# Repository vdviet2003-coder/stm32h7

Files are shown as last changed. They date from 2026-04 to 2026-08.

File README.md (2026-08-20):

# STM32H7 Sensorless FOC Motor Control

Firmware điều khiển động cơ PMSM theo phương pháp **Field-Oriented Control (FOC) không cảm biến vị trí (sensorless)** chạy trên vi điều khiển **STM32H723ZGTx**, sử dụng Sliding Mode Observer (SMO) để ước lượng góc và tốc độ rotor.

---
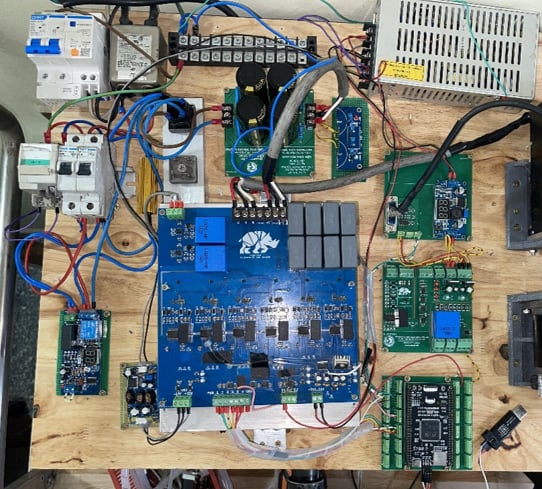
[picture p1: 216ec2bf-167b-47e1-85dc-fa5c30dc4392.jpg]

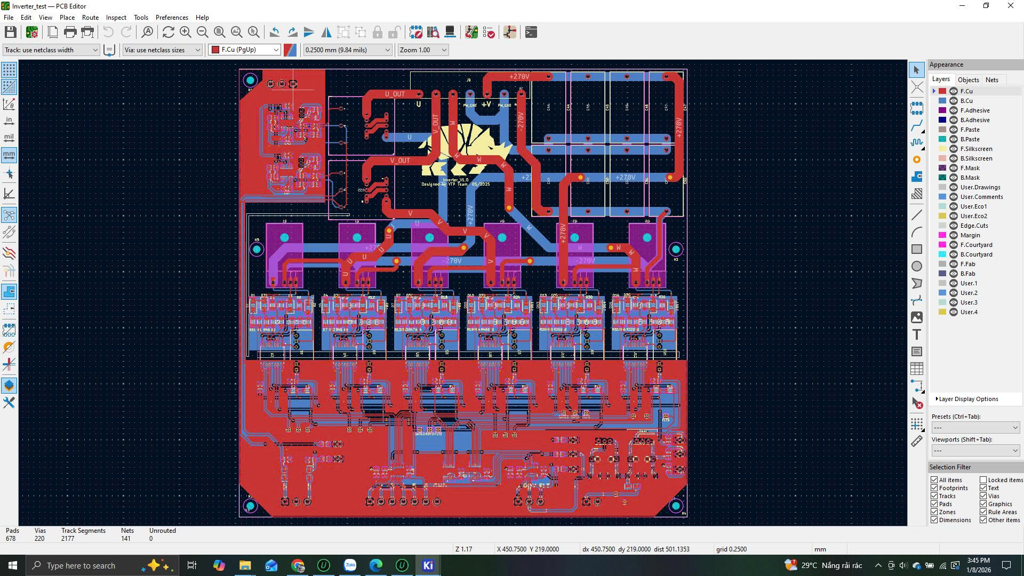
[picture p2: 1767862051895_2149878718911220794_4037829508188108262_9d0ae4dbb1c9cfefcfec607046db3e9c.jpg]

## Mục lục

1. [Tổng quan hệ thống](#1-tổng-quan-hệ-thống)
2. [Phần cứng và thông số động cơ](#2-phần-cứng-và-thông-số-động-cơ)
3. [Cấu trúc thư mục](#3-cấu-trúc-thư-mục)
4. [Sơ đồ khối điều khiển](#4-sơ-đồ-khối-điều-khiển)
5. [Luồng thực thi chính](#5-luồng-thực-thi-chính)
6. [Các module và logic chi tiết](#6-các-module-và-logic-chi-tiết)
   - 6.1 [conf.h – Cấu hình toàn cục](#61-confh--cấu-hình-toàn-cục)
   - 6.2 [FOC Transform – Clarke & Park](#62-foc-transform--clarke--park)
   - 6.3 [SVPWM – Space Vector PWM](#63-svpwm--space-vector-pwm)
   - 6.4 [ADC Driver – Đo dòng điện](#64-adc-driver--đo-dòng-điện)
   - 6.5 [Sensor – Hall & Encoder](#65-sensor--hall--encoder)
   - 6.6 [SMO – Sliding Mode Observer](#66-smo--sliding-mode-observer)
   - 6.7 [PID Controller](#67-pid-controller)
   - 6.8 [PI Clamping Controller](#68-pi-clamping-controller)
   - 6.9 [Speed Ramp Profiles](#69-speed-ramp-profiles)
   - 6.10 [UART DMA Library](#610-uart-dma-library)
7. [Máy trạng thái điều khiển (state machine)](#7-máy-trạng-thái-điều-khiển-state-machine)
   - 7.1 [Trạng thái chính (state)](#71-trạng-thái-chính-state)
   - 7.2 [Trạng thái SMO sensorless (state_smo)](#72-trạng-thái-smo-sensorless-state_smo)
8. [Cấu hình Timer và Ngắt](#8-cấu-hình-timer-và-ngắt)
9. [Thông số bộ điều khiển PID](#9-thông-số-bộ-điều-khiển-pid)
10. [Cấu hình Clock hệ thống](#10-cấu-hình-clock-hệ-thống)
11. [Build và nạp firmware](#11-build-và-nạp-firmware)

---

## 1. Tổng quan hệ thống

Hệ thống thực hiện điều khiển FOC hoàn chỉnh gồm 3 vòng điều khiển lồng nhau:

```
Tốc độ đặt (RPM/rad·s⁻¹)
        │
        ▼
  [Vòng tốc độ - PID]
        │  iq_ref
        ▼
  [Vòng dòng iq - PID] ──► vq
  [Vòng dòng id - PID] ──► vd    (id_ref = 0, kiểm soát từ thông)
        │
        ▼
  [Inv. Park] ──► vα, vβ
        │
        ▼
    [SVPWM] ──► TIM1 (PWM 3 pha)
        │
        ▼
     Động cơ
        │
        ▼
  [ADC] ─── iu, iv, iw
  [SMO] ─── θe, ωe  (sensorless)
        │
  [Clarke + Park] ──► id, iq (phản hồi)
```

---

## 2. Phần cứng và thông số động cơ

| Tham số | Giá trị |
|---|---|
| Vi điều khiển | STM32H723ZGTx |
| Toolchain | Keil MDK-ARM |
| Điện áp DC bus (VDC) | 60 V |
| Số cặp cực | 4 |
| Điện trở stator (Rs) | 5.83 Ω |
| Điện cảm stator (Ls) | 12.23 mH |
| Từ thông nam châm vĩnh cửu (ψf) | 0.0756 Wb |
| Tần số PWM | 20 kHz |
| Tần số vòng FOC | 40 kHz |
| Cảm biến dòng | LA-25-NP (Hall effect) |
| Điện trở đo | 120 Ω |
| Tỉ số biến đổi | 1:1000 (3 mA/A) |

### Phân công GPIO Hall sensor

| Tín hiệu | GPIO | Pin |
|---|---|-----|
| Hall U | GPIOD | PIN_12 |
| Hall V | GPIOD | PIN_13 |
| Hall W | GPIOD | PIN_14 |

---

## 3. Cấu trúc thư mục

```
no encoder/
└── GPIO/
    ├── Core/
    │   ├── Inc/           # Header STM32 HAL (adc.h, tim.h, gpio.h, ...)
    │   └── Src/
    │       ├── main.c     # Vòng lặp chính, FOC ISR, khởi tạo
    │       ├── adc.c      # Cấu hình ADC HAL (injected mode)
    │       ├── tim.c      # Cấu hình Timer HAL
    │       ├── gpio.c     # Cấu hình GPIO
    │       ├── dma.c      # Cấu hình DMA
    │       └── usart.c    # Cấu hình UART
    ├── MDK-ARM/           # Mã nguồn ứng dụng + project Keil
    │   ├── conf.h         # *** Toàn bộ thông số hệ thống ***
    │   ├── foc_transform.c/h   # Clarke, Park, Inv.Park transforms
    │   ├── svpwm.c/h           # SVPWM 6 sector + bù dead-time
    │   ├── adc_driver.c/h      # Đọc dòng từ LA-25-NP
    │   ├── sensor.c/h          # Hall sensor + Encoder ABZ
    │   ├── smo.c/h             # Sliding Mode Observer
    │   ├── pid.c/h             # PID Tustin + anti-windup
    │   ├── pi_control.c/h      # PI clamping
    │   ├── scurve_ramp.c/h     # S-curve tốc độ
    │   ├── multi_ramp.c/h      # Multi-segment ramp
    │   └── uart_dma_lib.c/h    # UART DMA gửi/nhận
    └── Drivers/
        ├── CMSIS/         # CMSIS core, DSP library
        └── STM32H7xx_HAL_Driver/  # HAL drivers
```

---

## 4. Sơ đồ khối điều khiển

```
                    ┌─────────────────────────────────────────────┐
                    │               FOC LOOP (40 kHz - TIM6)      │
                    │                                             │
speed_ref ──►[Ramp]──►[PID_speed]──► iq_ref                     │
                                        │                        │
              id_ref=0 ───────────────► [PID_id] ──► vd          │
                    iq_ref ──────────► [PID_iq] ──► vq           │
                                                     │           │
                                              [Inv.Park(θe)]     │
                                                     │           │
                                              [SVPWM] ──► TIM1   │
                                                                 │
    ADC ──► [Clarke] ──► iα,iβ ──► [Park(θe)] ──► id, iq        │
                  │                                              │
                  └──► [SMO] ──► θe, ωe (sensorless feedback)   │
                    └─────────────────────────────────────────────┘
```

---

## 5. Luồng thực thi chính

### `main()` – Khởi tạo một lần

```
1. MPU_Config()           – Cấu hình vùng bộ nhớ (DMA non-cacheable)
2. SystemClock_Config()   – PLL: HSE → 440 MHz SYSCLK
3. MX_*_Init()            – Khởi tạo tất cả ngoại vi HAL
4. SVPWM_Init()           – Cài đặt TIM1 center-aligned PWM
5. SVPWM_Start()          – Bật PWM 3 pha + complementary
6. ADC_Driver_Init()      – Khởi động ADC injected mode
7. ADC_Driver_CalibrateOffset() – Lấy 100,000 mẫu để tính offset
8. Hall_Sensor_Init()     – Đọc trạng thái Hall ban đầu
9. Encoder_Sensor_Init()  – Cấu hình TIM2 (encoder mode)
10. UART_DMA_Init()       – Bật UART1 DMA RX/TX
11. PID_Init(x3)          – Khởi tạo 3 vòng PID (Id, Iq, Speed)
12. SMO_Init()            – Khởi tạo Sliding Mode Observer
13. while(1) {}           – Vòng lặp trống (mọi xử lý qua ISR)
```

---

## 6. Các module và logic chi tiết

### 6.1 `conf.h` – Cấu hình toàn cục

File duy nhất chứa tất cả hằng số hệ thống. Thay đổi thông số ở đây sẽ tác động toàn bộ firmware.

```c
#define POLE_PAIRS          4.0f
#define MOTOR_PWM_FREQ      20000.0f   // Hz
#define MOTOR_SPEED_CALC_FREQ 40000.0f // Hz (vòng FOC)
#define MOTOR_RS            5.83f      // Ω
#define MOTOR_LS            0.01223f   // H
#define MOTOR_PSI_F         0.075595f  // Wb
#define VDC_BUS             60.0f      // V
```

---

### 6.2 FOC Transform – Clarke & Park

**File**: `foc_transform.c/h`

Thực hiện các phép biến đổi tọa độ cơ bản của FOC:

#### Clarke Transform (3 pha → αβ cố định)
$$i_\alpha = \frac{2}{3}i_u - \frac{1}{3}i_v - \frac{1}{3}i_w$$
$$i_\beta = \frac{1}{\sqrt{3}}(i_v - i_w)$$

#### Park Transform (αβ → dq quay theo rotor)
$$i_d = i_\alpha \cos\theta_e + i_\beta \sin\theta_e$$
$$i_q = -i_\alpha \sin\theta_e + i_\beta \cos\theta_e$$

#### Inverse Park (dq → αβ)
$$v_\alpha = v_d \cos\theta_e - v_q \sin\theta_e$$
$$v_\beta = v_d \sin\theta_e + v_q \cos\theta_e$$

> **Lưu ý**: Dùng biến đổi **amplitude-invariant** (không nhân 2/3), phù hợp với điều khiển dòng trực tiếp.

---

### 6.3 SVPWM – Space Vector PWM

**File**: `svpwm.c/h`

Thuật toán SVPWM 6 sector, center-aligned, với bù dead-time tự động.

#### Các bước tính toán:

1. **Xác định sector** – Dùng phương pháp dấu (Sign Method):
   ```
   U1 = Vβ
   U2 = (√3/2)·Vα - 0.5·Vβ
   U3 = -(√3/2)·Vα - 0.5·Vβ
   N = sign(U1) + 2·sign(U2) + 4·sign(U3)  → tra bảng sector_table[]
   ```

2. **Tính thời gian vector X, Y, Z** (chuẩn hóa):
   $$X = \frac{\sqrt{3} V_\beta}{V_{DC}}, \quad Y = \frac{1.5V_\alpha + 0.5\sqrt{3}V_\beta}{V_{DC}}, \quad Z = \frac{1.5V_\alpha - 0.5\sqrt{3}V_\beta}{V_{DC}}$$

3. **Gán Tx, Ty theo sector** và xử lý overmodulation (chuẩn hóa nếu Tx+Ty > 1)

4. **Tính duty cycle 3 pha**:
   $$T_a = 0.5 + \frac{V_\alpha}{V_{DC}}, \quad T_b = 0.5 + \frac{-0.5V_\alpha + \frac{\sqrt{3}}{2}V_\beta}{V_{DC}}$$

5. **Bù dead-time** (tự động theo chiều dòng điện):
   - Dead-time: 0.484 µs (= 133 chu kỳ / 275 MHz)
   - Điện áp diode: 0.8 V
   - Bù dương/âm tùy thuộc vào dấu dòng pha

6. **Ghi CCR** vào TIM1 (Center-aligned mode)

---

### 6.4 ADC Driver – Đo dòng điện

**File**: `adc_driver.c/h`

Đọc dòng điện từ 3 cảm biến **LA-25-NP** (Hall effect, ratio 1:1000) qua ADC injected mode đồng bộ với PWM.

#### Công thức chuyển đổi:
$$I_P = \frac{2 \cdot V_{ADC} + V_{offset}}{-R_m \cdot n} = \frac{2 \cdot V_{ADC} - 2.5}{-120 \times 0.003}$$

Trong đó:
- $V_{ADC}$: điện áp đọc từ ADC (0..3.3V)
- $V_{offset}$ = -2.5 V (điểm zero của cảm biến)
- $R_m$ = 120 Ω (điện trở đo)
- $n$ = 0.003 (tỉ số biến đổi = 3mA/A)

#### Hiệu chỉnh offset:
Khi khởi động, `ADC_Driver_CalibrateOffset()` lấy **100,000 mẫu** ở trạng thái không tải để xác định giá trị offset DC, bù vào các lần đọc sau.

---

### 6.5 Sensor – Hall & Encoder

**File**: `sensor.c/h`

#### Hall Sensor
- 3 bit Hall (U, V, W) → 6 bước (step 1..6)
- Mỗi bước tương ứng góc điện 60°
- `HallSensor_Update()` gọi trong `HAL_TIM_IC_CaptureCallback` (TIM4)
- `Sensor_Get_Electrical_Angle_Hall()` trả về góc điện (rad)

| Step | Góc điện |
|---|---|
| 1 | 0° |
| 2 | 60° |
| 3 | 120° |
| 4 | 180° |
| 5 | 240° |
| 6 | 300° |

#### Encoder ABZ
- TIM2 (32-bit) ở chế độ encoder quadrature
- 2500 PPR × 4 = 10,000 counts/vòng cơ
- `EncoderSensor_Update()` gọi trong TIM3 ISR (1 kHz)
- Hỗ trợ 3 phương pháp tính tốc độ:
  - **M method**: đếm xung trong thời gian cố định (tốc độ cao)
  - **T method**: đo thời gian giữa xung (tốc độ thấp)
  - **M/T method**: kết hợp hai phương pháp
  - **AUTO**: tự động chọn theo tốc độ

#### Bù trễ góc (Angle Prediction)
Trong vòng FOC, góc điện được dự đoán trước để bù trễ tính toán và ADC:
$$\theta_{pred} = \theta_{enc} + \omega_e \cdot (T_s + t_{delay})$$
Trong đó $t_{delay}$ = 3.87 µs (trễ ADC + tính toán).

---

### 6.6 SMO – Sliding Mode Observer

**File**: `smo.c/h`

Observer phi tuyến để ước lượng góc và tốc độ rotor **không cần encoder vật lý**. Triển khai theo mô hình dòng điện stator trong hệ tọa độ tĩnh αβ, kết hợp bộ lọc thông thấp và PLL để trích xuất sức phản điện (back-EMF).

---

#### Nguyên lý tổng quát

```
  [u_α, u_β]           [i_α, i_β]
       │                    │
       ▼                    │
  ┌─────────────────┐       │
  │  Mô hình dòng   │◄──────┘   (sai lệch → z_α, z_β)
  │  điện stator    │
  │  (Euler)        │──► [î_α, î_β]
  └────────┬────────┘
           │ z_α, z_β (sliding output)
           ▼
     [LPF 500 Hz]──► [ê_α, ê_β]  (back-EMF ước lượng)
           │
           ▼
       [PLL 200 Hz]──► θ_est, ω_est
           │
           ▼
   [Bù pha LPF]──► θ_compensated
```

---

#### Bước 1 – Hàm trượt (Sliding function) với deadzone

Để giảm chattering (dao động cao tần tại mặt trượt), hàm sign được thay bằng hàm tuyến tính trong vùng deadzone:

```c
static inline float sign_function(float x, float deadzone) {
    if      (x >  deadzone) return  1.0f;
    else if (x < -deadzone) return -1.0f;
    else                    return  x / deadzone;  // tuyến tính trong [-dz, +dz]
}
```

Ngõ ra khuếch đại trượt:

$$
z_{\alpha} = K_s \cdot \text{sign}(i_{\alpha,est} - i_{\alpha},\ 0.1\,\text{A})
$$

$$
z_{\beta} = K_s \cdot \text{sign}(i_{\beta,est} - i_{\beta},\ 0.1\,\text{A})
$$

Hệ số trượt $K_s$ chọn đủ lớn để đảm bảo điều kiện trượt:
$$K_s = 1.5 \cdot \omega_{max,elec} \cdot \psi_f \quad [\text{V}]$$

Ví dụ: $\omega_{max}$ = 3000 RPM × 4 pp × 2π/60 ≈ 1257 rad/s → $K_s = 1.5 \times 1257 \times 0.0756 \approx 142\,\text{V}$

---

#### Bước 2 – Mô hình dòng điện stator (tích phân Euler)

$$\hat{i}_{\alpha}[k+1] = \hat{i}_{\alpha}[k] + \frac{T_s}{L_s}\left(u_\alpha - R_s \hat{i}_{\alpha}[k] - z_\alpha\right)$$
$$\hat{i}_{\beta}[k+1]  = \hat{i}_{\beta}[k]  + \frac{T_s}{L_s}\left(u_\beta  - R_s \hat{i}_{\beta}[k]  - z_\beta\right)$$

Khi đạt chế độ trượt ($s_\alpha \to 0$, $s_\beta \to 0$), $z_\alpha \approx e_\alpha$ và $z_\beta \approx e_\beta$ (sức phản điện thực).

---

#### Bước 3 – Lọc thông thấp trích xuất back-EMF

Bộ lọc IIR bậc 1 (forward Euler) với $f_c$ = 500 Hz:

$$
\hat{e}_{\alpha}[k] = \alpha_f \cdot z_{\alpha} + (1-\alpha_f) \cdot \hat{e}_{\alpha}[k-1]
$$

$$
\hat{e}_{\beta}[k] = \alpha_f \cdot z_{\beta} + (1-\alpha_f) \cdot \hat{e}_{\beta}[k-1]
$$

Hệ số lọc:
$$\alpha_f = \frac{\omega_c T_s}{1 + \omega_c T_s}, \quad \omega_c = 2\pi \times 500 \approx 3141.6\,\text{rad/s}$$

Tại $T_s = 25\,\mu\text{s}$: $\alpha_f \approx 0.0728$

> **Lưu ý**: Bộ lọc thông thấp gây trễ pha phụ thuộc tốc độ, được bù lại ở bước 5.

---

#### Bước 4 – PLL ước lượng góc và tốc độ

Tín hiệu lỗi PLL (cross-product):

$$
\varepsilon = \hat{e}_{\beta} \cos\hat{\theta} - \hat{e}_{\alpha} \sin\hat{\theta}
$$

Khi hội tụ: $\hat{\theta} \to \theta_{real}$ → $\varepsilon \to 0$.

Bộ điều khiển PI của PLL:
$$\hat{\omega} = K_{p,PLL} \cdot \varepsilon + K_{i,PLL} \cdot \int \varepsilon \, dt$$

Tích phân góc (Euler):
$$\hat{\theta}[k+1] = \hat{\theta}[k] + \hat{\omega} \cdot T_s$$

Chuẩn hóa về $[0, 2\pi)$ sau mỗi bước.

**Anti-windup tốc độ**: khi $|\hat{\omega}| > \omega_{max}$, giới hạn cứng và reset tích phân:
```c
if (omega_pll > smo->omega_max) {
    omega_pll = smo->omega_max;
    smo->pll_integral = omega_pll / smo->Ki_pll;   // back-calculation
}
```

**Thông số PLL** (thiết kế theo $\zeta = 1/\sqrt{2}$, $f_n$ = 200 Hz):

| Tham số | Công thức | Giá trị |
|---|---|---|
| $\omega_n$ | $2\pi \times 200$ | 1256.6 rad/s |
| $K_{p,PLL}$ | $\sqrt{2} \cdot \omega_n$ | ≈ 1777 |
| $K_{i,PLL}$ | $\omega_n^2$ | ≈ 1.58 × 10⁶ |

---

#### Bước 5 – Bù pha bộ lọc thông thấp (`SMO_GetCompensatedTheta`)

Bộ lọc thông thấp 500 Hz gây trễ pha phụ thuộc tốc độ. Góc thực được bù động:
$$\phi_{delay} = \arctan\!\left(\frac{\hat{\omega}}{\omega_c}\right)$$
$$\theta_{comp} = \hat{\theta} + \phi_{delay}$$

```c
float SMO_GetCompensatedTheta(SMO_Handle *smo) {
    float wc = 2.0f * M_PI * smo->fc_filter;
    float phase_delay = atan2f(smo->omega_est, wc);
    return smo->theta_est + phase_delay;
}
```

> Khác với xấp xỉ cố định $+\pi/2$, cách này bù chính xác ở mọi tốc độ: khi $\hat{\omega} \ll \omega_c$ thì $\phi \to 0$; khi $\hat{\omega} \gg \omega_c$ thì $\phi \to \pi/2$.

---

#### Tóm tắt cấu trúc `SMO_Handle`

| Trường | Ý nghĩa | Đơn vị |
|---|---|---|
| `Rs`, `Ls`, `psi_f` | Thông số điện động cơ | Ω, H, Wb |
| `pole_pairs` | Số cặp cực | – |
| `Ks` | Hệ số khuếch đại trượt | V |
| `fc_filter`, `alpha_filter` | Bộ lọc LPF 500 Hz | Hz, – |
| `Kp_pll`, `Ki_pll` | Gains PI của PLL | – |
| `ialpha_est`, `ibeta_est` | Dòng ước lượng | A |
| `ealpha_est`, `ebeta_est` | Back-EMF ước lượng | V |
| `theta_est` | Góc điện ước lượng | rad |
| `omega_est` | Tốc độ điện ước lượng | rad/s |
| `pll_integral` | Tích phân PLL | – |
| `omega_max`, `omega_min` | Giới hạn tốc độ điện | rad/s |

---

#### API

| Hàm | Mô tả |
|-----|---|
| `SMO_Init(...)` | Khởi tạo, tự tính Ks, α_filter, Kp/Ki_pll |
| `SMO_Update(smo, uα, uβ, iα, iβ, dt)` | Gọi mỗi chu kỳ FOC (40 kHz) |
| `SMO_GetCompensatedTheta(smo)` | Trả về góc đã bù trễ LPF (rad) |
| `SMO_GetOmega(smo)` | Trả về tốc độ điện (rad/s) |
| `SMO_GetSpeedRPM(smo)` | Trả về tốc độ cơ (RPM) |

---

### 6.7 PID Controller

**File**: `pid.c/h`

Bộ điều khiển PID rời rạc dùng **Tustin (bilinear) discretization** để bảo toàn tính ổn định.

#### Rời rạc hóa Tustin:
$$u[k] = u[k-1] + \alpha \cdot e[k] + \beta \cdot e[k-1] + \gamma \cdot e[k-2]$$

Trong đó:
$$\alpha = K_p + \frac{K_i T}{2} + \frac{2K_d}{T}, \quad \beta = K_i T - \frac{4K_d}{T}, \quad \gamma = -K_p + \frac{K_i T}{2} + \frac{2K_d}{T}$$

#### Anti-windup:
Khi ngõ ra bão hòa (|u| = u_max), bộ tích phân tạm dừng (conditional integration).

---

### 6.8 PI Clamping Controller

**File**: `pi_control.c/h`

Bộ PI đơn giản với clamping (giới hạn cứng ngõ ra):
$$I_{prev} = I_{prev} + K_i \cdot T_s \cdot e$$
$$u = \text{clamp}(K_p \cdot e + I_{prev}, U_{min}, U_{max})$$

Dùng làm bộ điều khiển dự phòng thay thế cho PID trong trường hợp cần tuning nhanh.

---

### 6.9 Speed Ramp Profiles

#### S-Curve Ramp (`scurve_ramp.c/h`)
Tạo profile tốc độ dạng chữ S để tránh thay đổi đột ngột:
- Tham số: gia tốc tăng, gia tốc giảm, hằng số thời gian lọc τ
- Lọc exponential qua linear ramp → output mượt mà

#### Multi-Segment Ramp (`multi_ramp.c/h`)
Gia tốc khác nhau ở các vùng tốc độ khác nhau:
- Dưới ngưỡng (`threshold`): dùng `AccUp_1`, `AccDown_1` (gia tốc thấp vùng thấp tốc)
- Trên ngưỡng: dùng `AccUp_2`, `AccDown_2` (gia tốc cao vùng cao tốc)

Cấu hình mặc định: `threshold=5`, `up1=10`, `up2=10`, `down1=20`, `down2=20` (rad/s²)

---

### 6.10 UART DMA Library

**File**: `uart_dma_lib.c/h`

Giao tiếp UART1 bằng DMA không chặn (non-blocking):
- **TX**: Gửi chuỗi/dữ liệu qua DMA, không chờ
- **RX**: Nhận bằng DMA + IDLE interrupt để phát hiện kết thúc frame
- Hỗ trợ callback: `UART_DMA_RegisterRxCallback()` để xử lý dữ liệu nhận

---

## 7. Máy trạng thái điều khiển (State Machine)

### 7.1 Trạng thái chính (`state`)

Biến `state` điều khiển chế độ hoạt động của vòng FOC (TIM6 ISR, 40kHz):

```
┌─────────────────────────────────────────────────────────────────────┐
│  state = 0  │  DỪNG – PWM output = 0, reset SMO, tắt LED          │
├─────────────────────────────────────────────────────────────────────┤
│  state = 1  │  ALIGN – Căn chỉnh rotor:                           │
│             │  · InvPark(Id=0.8A, Iq=0, θ=0) → vα, vβ            │
│             │  · Reset encoder sau khi căn                         │
├─────────────────────────────────────────────────────────────────────┤
│  state = 2  │  CLOSED LOOP với Encoder:                           │
│             │  · Clarke → Park(θ_encoder_predicted)               │
│             │  · PID_speed → iq_ref                               │
│             │  · PID_iq, PID_id → vq, vd                         │
│             │  · InvPark → SVPWM                                  │
├─────────────────────────────────────────────────────────────────────┤
│  state = 3  │  OPEN LOOP điện áp:                                 │
│             │  · Dùng vd, vq đặt thủ công                        │
│             │  · InvPark(vd, vq, θ_encoder) → SVPWM              │
├─────────────────────────────────────────────────────────────────────┤
│  state = 4  │  SENSORLESS FOC (SMO):                             │
│             │  · 4 sub-state: ALIGN → OPENLOOP → SWITCH → RUN   │
└─────────────────────────────────────────────────────────────────────┘
```

### 7.2 Trạng thái SMO sensorless (`state_smo`)

Khi `state = 4`, máy trạng thái con `state_smo` quản lý quá trình khởi động sensorless:

```
       ┌─────────┐  ss_align_timer ≥ 1s   ┌────────────┐
  ───► │ SS_ALIGN│ ──────────────────────► │ SS_OPENLOOP│
       │         │                         │            │
       │Id=0.8A  │                         │Tăng ω mỗi  │
       │Iq=0     │                         │100rad/s²  │
       │θe = 0   │                         │            │
       └─────────┘                         └──────┬─────┘
                                                  │ ω ≥ ω_min
                                                  ▼
                                           ┌────────────┐
                                           │ SS_SWITCH  │
                                           │            │
                                           │Chờ SMO hội │
                                           │tụ: |î-i|  │
                                           │  < 0.3A   │
                                           └──────┬─────┘
                                                  │ hội tụ
                                                  ▼
                                           ┌────────────┐
                                           │  SS_RUN    │
                                           │            │
                                           │θe = SMO    │
                                           │ωe = SMO    │
                                           │PID_speed   │
                                           └────────────┘
```

#### Chi tiết từng sub-state:

| Sub-state | Góc θe | Dòng đặt | Điều kiện chuyển |
|---|---|---|---|
| `SS_ALIGN` | 0 rad (cố định) | Id=0.8A, Iq=0 | timer ≥ 1 giây |
| `SS_OPENLOOP` | Tăng dần (tích phân ω) | Id=0.8A, Iq=0 | ω_openloop ≥ ω_min (900 RPM × 4pp) |
| `SS_SWITCH` | Open-loop giữ nguyên | Id=0.8A, Iq=0 | \|î_α - i_α\| < 0.3A **và** \|î_β - i_β\| < 0.3A |
| `SS_RUN` | `SMO_GetCompensatedTheta()` | Id=0, Iq=PID_speed | – |

---

## 8. Cấu hình Timer và Ngắt

| Timer | Chức năng | Tần số / Mode |
|---|---|---|
| **TIM1** | SVPWM 3 pha + complementary | 20 kHz, center-aligned, PWM mode |
| **TIM2** | Encoder ABZ (32-bit) | Encoder interface mode, 10,000 cnt/rev |
| **TIM3** | Cập nhật tốc độ encoder | 1 kHz, base timer interrupt |
| **TIM4** | Hall sensor input capture | Capture trên cạnh lên của Hall |
| **TIM5** | Encoder capture (Z pulse) | Input capture channel 3 |
| **TIM6** | **FOC loop interrupt** | **40 kHz** – tất cả xử lý FOC |
| **TIM12** | Z-pulse (dự phòng) | – |

### ISR quan trọng

```c
// Gọi 40,000 lần/giây – xử lý FOC toàn bộ
void HAL_TIM_PeriodElapsedCallback(TIM_HandleTypeDef *htim) {
    if (htim->Instance == TIM6) {
        // 1. Đọc cảm biến (Hall, Encoder, ADC)
        // 2. Chạy máy trạng thái state/state_smo
        // 3. Clarke → Park → PID → InvPark → SVPWM
    }
    if (htim->Instance == TIM3) {
        EncoderSensor_Update();   // Tính tốc độ M/T
    }
}
```

---

## 9. Thông số bộ điều khiển PID

| Vòng | Kp | Ki | Kd | Giới hạn ngõ ra |
|---|----|----|----|---|
| **PID_id** (dòng d-axis) | 12.0 | 5830 | 0 | ±VDC/√3 = ±34.64 V |
| **PID_iq** (dòng q-axis) | 12.0 | 5830 | 0 | ±VDC/√3 = ±34.64 V |
| **PID_speed** (tốc độ) | 0.0053 | 2.37 | 0 | ±2.8 A |

> **Thiết kế vòng dòng**: Kp và Ki được tính theo phương pháp pole-zero cancellation:  
> $K_p = \frac{L_s}{\tau_{cl} \cdot T_s}$, $K_i = \frac{R_s}{\tau_{cl} \cdot T_s}$  
> với băng thông đóng $f_{cl}$ ~ 1 kHz.

---

## 10. Cấu hình Clock hệ thống

```
HSE (8 MHz) → PLL1:
  PLLM = 2  → VCI = 4 MHz
  PLLN = 44 → VCO = 176 MHz × 2 = 352 MHz  (wide VCO)
  PLLP = 1  → SYSCLK = 440 MHz
  AHB  /2   → HCLK  = 220 MHz
  APB1 /2   → PCLK1 = 110 MHz  (TIM2, TIM3, TIM4, TIM5, TIM6, TIM12)
  APB2 /2   → PCLK2 = 110 MHz  (TIM1, USART1)
```

- **Điện áp lõi**: Scale 0 (hiệu suất cao nhất)
- **Flash latency**: 3 wait states

---

## 11. Build và nạp firmware

### Yêu cầu
- **Keil MDK-ARM** v5.38 trở lên
- **STM32H7 Device Family Pack** (DFP)
- **ST-Link** hoặc J-Link debugger
- **CMSIS-DSP Library** (đã bao gồm trong `Drivers/CMSIS/DSP/`)

### Build
1. Mở `GPIO/MDK-ARM/GPIO.uvprojx` trong Keil uVision
2. Chọn target **GPIO**
3. Build: `F7` hoặc `Project → Build Target`

### Nạp và Debug
1. Kết nối ST-Link với board STM32H7
2. Flash: `Flash → Download` hoặc `F8`
3. Debug: `Debug → Start/Stop Debug Session` (`Ctrl+F5`)

### UART Monitor
- **UART1**, **115200 baud**, 8N1
- Khi khởi động, board gửi: `"UART DMA with IDLE+HT/TC ready\r\n"`
- Có thể gửi lệnh để thay đổi `state` và `speed_ref_rads`

---

## Ghi chú kỹ thuật

- **Dead-time**: 133 chu kỳ clock (≈ 0.484 µs tại 275 MHz APB) được bù tự động theo chiều dòng
- **ADC Injected mode**: ADC triggered đồng bộ với PWM (đỉnh counter TIM1) để lấy mẫu tại điểm tốt nhất (giữa thời gian dẫn)
- **Câu 3 pha từ 2 cảm biến**: `iw = -iu - iv` (định luật Kirchhoff), chỉ cần 2 cảm biến LA-25-NP vật lý
- **SMO ω_min**: 900 RPM × 4 cặp cực × 2π/60 ≈ 376 rad/s điện – tốc độ tối thiểu để SMO hội tụ ổn định
- **MPU**: Cấu hình vùng bộ nhớ DMA là non-cacheable để tránh data coherency issue với DMA

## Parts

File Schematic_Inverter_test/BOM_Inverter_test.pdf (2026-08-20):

Reference | Qty | Value
C1,C2,C3,C5,C8,C9,C10,C12,C15,C16,C17,C19,C22,C23,C24,C26,C29,C30,C31,C33,C36,C37,C38,C40,C69,C70 26 4.7u C4,C6,C11,C13,C18,C20,C25,C27,C32,C34,C39,C41,C53,C54,C55,C56,C57,C58 18 1u
C7,C14,C21,C28,C35,C42 | 6 220p
C43,C48,C67,C68 | 4 100n
C44,C45,C46,C47,C49,C50,C51,C52 8 106J
C59,C62,C63,C66 | 4 10u
C60,C61,C64,C65 | 4 1u
D1,D4,D7,D10,D13,D16,D22,D26,D27 9 B160-E3
D2,D5,D8,D11,D14,D17 | 6 D
D3,D6,D9,D12,D15,D18 | 6 D_Zener 4V7
D19,D20,D21,D23,D24,D25,D28,D29 8 LED
H1,H2,H3,H4 | 4 MountingHole
J1,J7 | 2 Screw_Terminal_01x03
J2 | 1 541V
J3 | 1 Screw_Terminal_01x07
J4 | 1 Alarm
J5 | 1 24V
J6,J8 | 2 Screw_Terminal_01x04
Q1,Q2,Q3,Q4,Q5,Q6 | 6 NC2M120C20HT
R1,R2,R7,R8,R13,R14,R19,R20,R25,R26,R31,R32,R45,R46,R47,R48,R49,R50,R51,R52,R53,R54,R55,R56 24 10 R3,R5,R9,R11,R15,R17,R21,R23,R27,R29,R33,R35,R37,R38 14 10k
R4,R10,R16,R22,R28,R34 | 6 10K
R6,R12,R18,R24,R30,R36,R71,R728 1K
R39,R40,R43 | 3 220
R41,R44 | 2 100
R42 | 1 1k5
R57,R58,R63,R64,R65,R66,R67,R68,R69,R70 10 10K
R59,R61 | 2 120k
R60,R62 | 2 160k
Rm1,Rm2 | 2 120
U1,U3,U5,U7,U9,U11 | 6 MGJ2D
U2,U4,U6,U8,U10,U12 | 6 1ED3321MC12NXUMA1
U13,U14 | 2 TXB0106PW
U15,U16 | 2 SN74HCS30PWR
U17 | 1 L7805
U18 | 1 LM1117T-3.3
U19,U20 | 2 LM385Z-ADJ
U21,U22 | 2 LA25-NP
U23,U24 | 2 OPA994IDR

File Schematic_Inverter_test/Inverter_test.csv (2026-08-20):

Reference | Qty | Value
24V1,FLT1,FLT2,FLT3,FLT4,FLT5,FLT6,GATE1,GATE2,GATE3,GATE4,GATE5,GATE6,GND1,RDY1,RDY2,RDY3,RDY4,RDY5,RDY6 | 20 | TestPoint
C1,C2,C3,C5,C8,C9,C10,C12,C15,C16,C17,C19,C22,C23,C24,C26,C29,C30,C31,C33,C36,C37,C38,C40,C69,C70 | 26 | 4.7u
C4,C6,C11,C13,C18,C20,C25,C27,C32,C34,C39,C41,C53,C54,C55,C56,C57,C58 | 18 | 1u
C7,C14,C21,C28,C35,C42 | 6 | 220p
C43,C48,C67,C68 | 4 | 100n
C44,C45,C46,C47,C49,C50,C51,C52 | 8 | 106J
C59,C62,C63,C66 | 4 | 10u t? hoá
C60,C61,C64,C65 | 4 | 1u t? k?o
D1,D4,D7,D10,D13,D16,D22,D26,D27,D30,D31,D32,D33,D34,D35 | 15 | Diode Shotky 5A 40V
D2,D5,D8,D11,D14,D17 | 6 | D th??ng
D3,D6,D9,D12,D15,D18 | 6 | D_Zener 10V
D19,D20,D21,D23,D24,D25,D28,D29 | 8 | LED
H1,H2,H3,H4,H5 | 5 | MountingHole
J1,J7 | 2 | Screw_Terminal_01x03
J3 | 1 | Screw_Terminal_01x07
J4 | 1 | Alarm
J5 | 1 | 24V
J9 | 1 | Screw_Terminal_01x07
Q1,Q2,Q3,Q4,Q5,Q6 | 6 | NC2M120C20HT
R1,R2,R7,R8,R13,R14,R19,R20,R25,R26,R31,R32,R45,R46,R47,R48,R49,R50,R51,R52,R53,R54,R55,R56 | 24 | 10R
R3,R5,R9,R11,R15,R17,R21,R23,R27,R29,R33,R35,R37,R38 | 14 | 10kR
R4,R10,R16,R22,R28,R34 | 6 | 10K
R6,R12,R18,R24,R30,R36,R71,R72 | 8 | 1K
R39,R40,R43 | 3 | 220R
R41,R44 | 2 | 100R
R42 | 1 | 1k5
R57,R58,R63,R64,R65,R66,R67,R68,R69,R70 | 10 | 10K
R59,R61 | 2 | 120k
R60,R62 | 2 | 160k
Rm1,Rm2 | 2 | 120R
U1,U3,U5,U7,U9,U11 | 6 | MGJ2D
U2,U4,U6,U8,U10,U12 | 6 | 1ED3321MC12NXUMA1
U13,U14 | 2 | TXB0106PW
U15,U16 | 2 | SN74HCS30PWR
U17 | 1 | L7805
U18 | 1 | LM1117T-3.3
U19,U20 | 2 | LM385Z-ADJ
U21,U22 | 2 | LA25-NP
U23,U24 | 2 | OPA994IDR

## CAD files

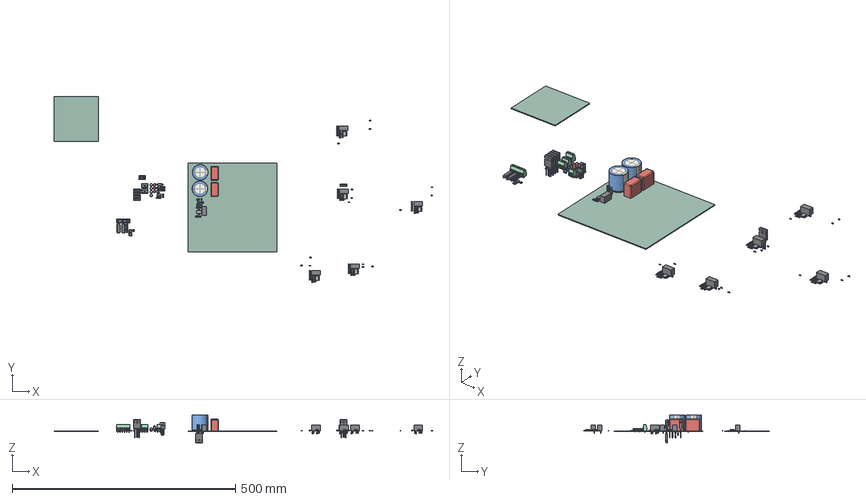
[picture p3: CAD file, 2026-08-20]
Schematic_Inverter_test/Inverter_test.step
848.2 x 415.3 x 62.0 mm
R_1206_3216Metric x 41
C_1206_3216Metric x 48
MGJ2_MUR x 6
LED_D5.0mm x 3
C_Disc_D5.0mm_W2.5mm_P5.00mm x 4
D_1206_3216Metric x 18
PG-DSO-16-40_INF x 6
CP_Radial_D35.0mm_P10.00mm_SnapIn x 2
TO-247-4_Vertical x 6
C_Rect_L31.5mm_W17.0mm_P27.50mm_MKS4 x 2
CP_Radial_D6.3mm_P2.50mm x 4
TO-220-3_Vertical x 2
TerminalBlock_Phoenix_MKDS-1,5-2_1x02_P5.00mm_Horizontal
TerminalBlock_Phoenix_MKDS-1,5-3_1x03_P5.00mm_Horizontal x 3
D_DO-27_P12.70mm_Horizontal
TSSOP-20_4.4x6.5mm_P0.65mm x 2
N14_TEX x 2
TerminalBlock_Phoenix_MKDS-1,5-6_1x06_P5.00mm_Horizontal
Inverter_test_copper
Inverter_test_silkscreen
Inverter_test_soldermask
Inverter_test_PCB_1
Inverter_test_PCB_2

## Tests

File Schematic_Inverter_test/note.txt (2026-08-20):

Min conductor Spacing ( khoảng cách tối thiểu )
+ 541V 	      :0.9251 mm  chọn 1mm
+ 24V,5V,3V3  :0.05   mm
Fusing Current (Dòng điện cháy đường dẫn)
+ 80A 	      : 6 mm
+ 6.5A	      : 0.6 mm
Conductor Properties (Đặc tính đường dẫn)

Thermal Management (Quản lý nhiệt)
Via Properties (Đặc tính lỗ thông tầng)
Conductor Impedance (Trở kháng đường dẫn)
Differential Pairs / XTALK (Cặp vi sai và nhiễu chéo)
PDN Calculator (Tính toán mạng phân phối điện)
Bandwidth & Max Er Effective Length (Băng thông và độ dài hiệu quả)

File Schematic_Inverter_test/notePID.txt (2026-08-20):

làm hàm code PID

gồm các biến như sau 
thời gian lấy mẫu: T
xung của encoder : EncoderCounter
Gía trị đặt : SetPoint
Gía trị hiện tại: CurrentPoint
Sai số hiện tại : E
Sai số trước đó 1 mẫu : E1
Sai số trước đó 2 mẫu : E2
các thông số của PID : alpha, beta, gamma, Kp,Kd,Ki;

xuất giá trị : Output,LastOutput

hàm PID
E = SetPoint - CurrentPoint
alpha = 2*T*Kp + K*T*T + 2*Kd
beta  = T*T*Ki - 4*Kd  - 2*T*Kp
gamma = 2*Kd

Output = ( alpha*E  + beta*E1 + gamma*E2 + 2*T*lastOutput)/(2*T);
lastOutput = Output
E2=E1
E1=E

hàm Park_1
Valfa = cos(Angle)*Vd - sin(Angle)*Vq
Vbeta = sin(Angle)*Vd + cos(Angle)*Vq
//
Id*cos(Angle)-Iq*sin(Angle)
Id*cos(Angle-2*pi/3)-Iq*sin(Angle-2*pi/3)
Id*cos(Angle+2*pi/3)-Iq*sin(Angle+2*pi/3)

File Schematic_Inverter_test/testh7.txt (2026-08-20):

/* USER CODE BEGIN Header */
/**
 ******************************************************************************
 * @file           : main.c
 * @brief          : Main program body
 ******************************************************************************
 * @attention
 *
 * Copyright (c) 2025 STMicroelectronics.
 * All rights reserved.
 *
 * This software is licensed under terms that can be found in the LICENSE file
 * in the root directory of this software component.
 * If no LICENSE file comes with this software, it is provided AS-IS.
 *
 ******************************************************************************
 */
/* USER CODE END Header */
/* Includes ------------------------------------------------------------------*/
#include "main.h"

/* Private includes ----------------------------------------------------------*/
/* USER CODE BEGIN Includes */
#include "arm_math.h"
#include "stdbool.h"
#include "stdio.h"
#include "stdlib.h"
#include "string.h"
/* USER CODE END Includes */

/* Private typedef -----------------------------------------------------------*/
/* USER CODE BEGIN PTD */
#define FSAMPLING    5000.0f     // tần số gọi SVPWM (5 kHz)
#define FOUT_TARGET  50.0f       // tần số điện áp mong muốn (Hz)
#define Pi 3.14159265359f

/* USER CODE END PTD */

/* Private define ------------------------------------------------------------*/
/* USER CODE BEGIN PD */

/* USER CODE END PD */

/* Private macro -------------------------------------------------------------*/
/* USER CODE BEGIN PM */

/* USER CODE END PM */

/* Private variables ---------------------------------------------------------*/

TIM_HandleTypeDef htim1;
TIM_HandleTypeDef htim3;

/* USER CODE BEGIN PV */
float Angle = 0.0f; // degree
float Angle_radian = 0.0f; // rad
float agl ; // // degree
float agl_radian ; // rad

float Vd = 0.0f;
float Vq = 5.0f;
float Vdc = 35.0f;
float Tperiod = 0.0f;
float Valpha , Vbeta , Vref ;
float Ta = 0.0f, Tb = 0.0f, T0 = 0.0f, T1 = 0.0f, T2 = 0.0f;
float u = 0.0f, v = 0.0f, w = 0.0f, g = 0.0f;
float Tsw1 = 0.0f, Tsw2 = 0.0f, Tsw3 = 0.0f;
uint8_t s;
/* USER CODE END PV */

/* Private function prototypes -----------------------------------------------*/
void SystemClock_Config(void);
static void MPU_Config(void);
static void MX_GPIO_Init(void);
static void MX_TIM1_Init(void);
static void MX_TIM3_Init(void);
/* USER CODE BEGIN PFP */

/* USER CODE END PFP */

/* Private user code ---------------------------------------------------------*/
/* USER CODE BEGIN 0 */
void Update_Tperiod(void)
{
    uint32_t tim_clk = 275000000;   // lấy clock thực tế của TIM1

    uint32_t prescaler = htim1.Init.Prescaler + 1U;
    uint32_t period    = htim1.Init.Period + 1U;

    // Nếu counter mode là center-aligned → period hiệu dụng gấp đôi
    if (htim1.Init.CounterMode == TIM_COUNTERMODE_CENTERALIGNED1 ||
        htim1.Init.CounterMode == TIM_COUNTERMODE_CENTERALIGNED2 ||
        htim1.Init.CounterMode == TIM_COUNTERMODE_CENTERALIGNED3)
    {
        period *= 2U;
    }

    Tperiod = ((float)prescaler * (float)period) / (float)tim_clk;
}
void SVPWM(void)
{
    Angle_radian = Angle * (Pi / 180.0f);
    Valpha = arm_cos_f32(Angle_radian) * Vd - arm_sin_f32(Angle_radian) * Vq;
    Vbeta  = arm_sin_f32(Angle_radian) * Vd + arm_cos_f32(Angle_radian) * Vq;

    arm_sqrt_f32(((Valpha * Valpha) + (Vbeta * Vbeta)), &Vref);
    agl_radian = atan2f(Vbeta, Valpha);
    agl = agl_radian * (180.0f / Pi);

    if (agl >= 0 && agl < 60)          
			s = 1;
    else if (agl >= 60 && agl < 120)   
			s = 2;
    else if (agl >= 120 && agl < 180)  
			s = 3;
    else if (agl >= -180 && agl < -120) 
			s = 4;
    else if (agl >= -120 && agl < -60)  
			s = 5;
    else if (agl >= -60 && agl < 0)     
			s = 6;
    else                 
			s = 0;

    // --- 4. Vector times ---
    Ta = T1 = (Tperiod * sqrtf(3.0f) / Vdc) * Vref *sinf((Pi * s / 3.0f) - agl_radian);

    Tb = T2 = (Tperiod * sqrtf(3.0f) / Vdc) * Vref *sinf(agl_radian - ((s - 1) * Pi / 3.0f));

    T0 = Tperiod - Ta - Tb;

    // --- 5. Intermediate values ---
    u = Tperiod - T0 / 2.0f;
    v = (T0 / 2.0f) + T2;
    w = T0 / 2.0f;
    g = (T0 / 2.0f) + T1;

    // --- 6. Switching times ---
    switch (s)
    {		
				case 0: Tsw1 = 0; Tsw2 = 0; Tsw3 = 0; break;
        case 1: Tsw1 = u; Tsw2 = v; Tsw3 = w; break;
        case 2: Tsw1 = g; Tsw2 = u; Tsw3 = w; break;
        case 3: Tsw1 = w; Tsw2 = u; Tsw3 = v; break;
        case 4: Tsw1 = w; Tsw2 = g; Tsw3 = u; break;
        case 5: Tsw1 = v; Tsw2 = w; Tsw3 = u; break;
        case 6: Tsw1 = u; Tsw2 = w; Tsw3 = g; break;
        
    }

    // --- 7. Mapping sang CCR ---
    uint32_t max_count = htim1.Init.Period;

    TIM1->CCR1 = (uint32_t)((Tsw1 / Tperiod) * max_count); // pha U
    TIM1->CCR2 = (uint32_t)((Tsw2 / Tperiod) * max_count); // pha V
    TIM1->CCR3 = (uint32_t)((Tsw3 / Tperiod) * max_count); // pha W

}

void HAL_TIM_PeriodElapsedCallback(TIM_HandleTypeDef *htim) {
    if (htim->Instance == TIM3) {
						SVPWM();
			        
    }
}
/* USER CODE END 0 */

/**
  * @brief  The application entry point.
  * @retval int
  */
int main(void)
{

  /* USER CODE BEGIN 1 */

  /* USER CODE END 1 */

  /* MPU Configuration--------------------------------------------------------*/
  MPU_Config();

  /* MCU Configuration--------------------------------------------------------*/

  /* Reset of all peripherals, Initializes the Flash interface and the Systick. */
  HAL_Init();

  /* USER CODE BEGIN Init */

  /* USER CODE END Init */

  /* Configure the system clock */
  SystemClock_Config();

  /* USER CODE BEGIN SysInit */

  /* USER CODE END SysInit */

  /* Initialize all configured peripherals */
  MX_GPIO_Init();
  MX_TIM1_Init();
  MX_TIM3_Init();
  /* USER CODE BEGIN 2 */
    HAL_TIM_PWM_Start(&htim1, TIM_CHANNEL_1);
    HAL_TIM_PWM_Start(&htim1, TIM_CHANNEL_2);
    HAL_TIM_PWM_Start(&htim1, TIM_CHANNEL_3);
    HAL_TIMEx_PWMN_Start(&htim1, TIM_CHANNEL_1);
    HAL_TIMEx_PWMN_Start(&htim1, TIM_CHANNEL_2);
    HAL_TIMEx_PWMN_Start(&htim1, TIM_CHANNEL_3);
    HAL_TIM_Base_Start_IT(&htim3);
		Update_Tperiod();
  /* USER CODE END 2 */

  /* Infinite loop */
  /* USER CODE BEGIN WHILE */
    while (1)
    {
    /* USER CODE END WHILE */

    /* USER CODE BEGIN 3 */
        HAL_GPIO_WritePin(GPIOA, GPIO_PIN_0, GPIO_PIN_SET);
    }
  /* USER CODE END 3 */
}

/**
  * @brief System Clock Configuration
  * @retval None
  */
void SystemClock_Config(void)
{
  RCC_OscInitTypeDef RCC_OscInitStruct = {0};
  RCC_ClkInitTypeDef RCC_ClkInitStruct = {0};

  /** Supply configuration update enable
  */
  HAL_PWREx_ConfigSupply(PWR_LDO_SUPPLY);

  /** Configure the main internal regulator output voltage
  */
  __HAL_PWR_VOLTAGESCALING_CONFIG(PWR_REGULATOR_VOLTAGE_SCALE0);

  while(!__HAL_PWR_GET_FLAG(PWR_FLAG_VOSRDY)) {}

  /** Initializes the RCC Oscillators according to the specified parameters
  * in the RCC_OscInitTypeDef structure.
  */
  RCC_OscInitStruct.OscillatorType = RCC_OSCILLATORTYPE_HSE;
  RCC_OscInitStruct.HSEState = RCC_HSE_ON;
  RCC_OscInitStruct.PLL.PLLState = RCC_PLL_ON;
  RCC_OscInitStruct.PLL.PLLSource = RCC_PLLSOURCE_HSE;
  RCC_OscInitStruct.PLL.PLLM = 2;
  RCC_OscInitStruct.PLL.PLLN = 44;
  RCC_OscInitStruct.PLL.PLLP = 1;
  RCC_OscInitStruct.PLL.PLLQ = 2;
  RCC_OscInitStruct.PLL.PLLR = 2;
  RCC_OscInitStruct.PLL.PLLRGE = RCC_PLL1VCIRANGE_3;
  RCC_OscInitStruct.PLL.PLLVCOSEL = RCC_PLL1VCOWIDE;
  RCC_OscInitStruct.PLL.PLLFRACN = 0;
  if (HAL_RCC_OscConfig(&RCC_OscInitStruct) != HAL_OK)
  {
    Error_Handler();
  }

  /** Initializes the CPU, AHB and APB buses clocks
  */
  RCC_ClkInitStruct.ClockType = RCC_CLOCKTYPE_HCLK|RCC_CLOCKTYPE_SYSCLK
                              |RCC_CLOCKTYPE_PCLK1|RCC_CLOCKTYPE_PCLK2
                              |RCC_CLOCKTYPE_D3PCLK1|RCC_CLOCKTYPE_D1PCLK1;
  RCC_ClkInitStruct.SYSCLKSource = RCC_SYSCLKSOURCE_PLLCLK;
  RCC_ClkInitStruct.SYSCLKDivider = RCC_SYSCLK_DIV1;
  RCC_ClkInitStruct.AHBCLKDivider = RCC_HCLK_DIV2;
  RCC_ClkInitStruct.APB3CLKDivider = RCC_APB3_DIV2;
  RCC_ClkInitStruct.APB1CLKDivider = RCC_APB1_DIV2;
  RCC_ClkInitStruct.APB2CLKDivider = RCC_APB2_DIV2;
  RCC_ClkInitStruct.APB4CLKDivider = RCC_APB4_DIV2;

  if (HAL_RCC_ClockConfig(&RCC_ClkInitStruct, FLASH_LATENCY_3) != HAL_OK)
  {
    Error_Handler();
  }
}

/**
  * @brief TIM1 Initialization Function
  * @param None
  * @retval None
  */
static void MX_TIM1_Init(void)
{

  /* USER CODE BEGIN TIM1_Init 0 */

  /* USER CODE END TIM1_Init 0 */

  TIM_ClockConfigTypeDef sClockSourceConfig = {0};
  TIM_MasterConfigTypeDef sMasterConfig = {0};
  TIM_OC_InitTypeDef sConfigOC = {0};
  TIM_BreakDeadTimeConfigTypeDef sBreakDeadTimeConfig = {0};

  /* USER CODE BEGIN TIM1_Init 1 */

  /* USER CODE END TIM1_Init 1 */
  htim1.Instance = TIM1;
  htim1.Init.Prescaler = 0;
  htim1.Init.CounterMode = TIM_COUNTERMODE_CENTERALIGNED1;
  htim1.Init.Period = 13749;
  htim1.Init.ClockDivision = TIM_CLOCKDIVISION_DIV2;
  htim1.Init.RepetitionCounter = 0;
  htim1.Init.AutoReloadPreload = TIM_AUTORELOAD_PRELOAD_DISABLE;
  if (HAL_TIM_Base_Init(&htim1) != HAL_OK)
  {
    Error_Handler();
  }
  sClockSourceConfig.ClockSource = TIM_CLOCKSOURCE_INTERNAL;
  if (HAL_TIM_ConfigClockSource(&htim1, &sClockSourceConfig) != HAL_OK)
  {
    Error_Handler();
  }
  if (HAL_TIM_PWM_Init(&htim1) != HAL_OK)
  {
    Error_Handler();
  }
  sMasterConfig.MasterOutputTrigger = TIM_TRGO_RESET;
  sMasterConfig.MasterOutputTrigger2 = TIM_TRGO2_RESET;
  sMasterConfig.MasterSlaveMode = TIM_MASTERSLAVEMODE_DISABLE;
  if (HAL_TIMEx_MasterConfigSynchronization(&htim1, &sMasterConfig) != HAL_OK)
  {
    Error_Handler();
  }
  sConfigOC.OCMode = TIM_OCMODE_PWM1;
  sConfigOC.Pulse = 0;
  sConfigOC.OCPolarity = TIM_OCPOLARITY_HIGH;
  sConfigOC.OCNPolarity = TIM_OCNPOLARITY_HIGH;
  sConfigOC.OCFastMode = TIM_OCFAST_DISABLE;
  sConfigOC.OCIdleState = TIM_OCIDLESTATE_RESET;
  sConfigOC.OCNIdleState = TIM_OCNIDLESTATE_RESET;
  if (HAL_TIM_PWM_ConfigChannel(&htim1, &sConfigOC, TIM_CHANNEL_1) != HAL_OK)
  {
    Error_Handler();
  }
  if (HAL_TIM_PWM_ConfigChannel(&htim1, &sConfigOC, TIM_CHANNEL_2) != HAL_OK)
  {
    Error_Handler();
  }
  if (HAL_TIM_PWM_ConfigChannel(&htim1, &sConfigOC, TIM_CHANNEL_3) != HAL_OK)
  {
    Error_Handler();
  }
  sBreakDeadTimeConfig.OffStateRunMode = TIM_OSSR_DISABLE;
  sBreakDeadTimeConfig.OffStateIDLEMode = TIM_OSSI_DISABLE;
  sBreakDeadTimeConfig.LockLevel = TIM_LOCKLEVEL_OFF;
  sBreakDeadTimeConfig.DeadTime = 100;
  sBreakDeadTimeConfig.BreakState = TIM_BREAK_DISABLE;
  sBreakDeadTimeConfig.BreakPolarity = TIM_BREAKPOLARITY_HIGH;
  sBreakDeadTimeConfig.BreakFilter = 0;
  sBreakDeadTimeConfig.Break2State = TIM_BREAK2_DISABLE;
  sBreakDeadTimeConfig.Break2Polarity = TIM_BREAK2POLARITY_HIGH;
  sBreakDeadTimeConfig.Break2Filter = 0;
  sBreakDeadTimeConfig.AutomaticOutput = TIM_AUTOMATICOUTPUT_DISABLE;
  if (HAL_TIMEx_ConfigBreakDeadTime(&htim1, &sBreakDeadTimeConfig) != HAL_OK)
  {
    Error_Handler();
  }
  /* USER CODE BEGIN TIM1_Init 2 */

  /* USER CODE END TIM1_Init 2 */
  HAL_TIM_MspPostInit(&htim1);

}

/**
  * @brief TIM3 Initialization Function
  * @param None
  * @retval None
  */
static void MX_TIM3_Init(void)
{

  /* USER CODE BEGIN TIM3_Init 0 */

  /* USER CODE END TIM3_Init 0 */

  TIM_ClockConfigTypeDef sClockSourceConfig = {0};
  TIM_MasterConfigTypeDef sMasterConfig = {0};

  /* USER CODE BEGIN TIM3_Init 1 */

  /* USER CODE END TIM3_Init 1 */
  htim3.Instance = TIM3;
  htim3.Init.Prescaler = 0;
  htim3.Init.CounterMode = TIM_COUNTERMODE_UP;
  htim3.Init.Period = 54999;
  htim3.Init.ClockDivision = TIM_CLOCKDIVISION_DIV1;
  htim3.Init.AutoReloadPreload = TIM_AUTORELOAD_PRELOAD_DISABLE;
  if (HAL_TIM_Base_Init(&htim3) != HAL_OK)
  {
    Error_Handler();
  }
  sClockSourceConfig.ClockSource = TIM_CLOCKSOURCE_INTERNAL;
  if (HAL_TIM_ConfigClockSource(&htim3, &sClockSourceConfig) != HAL_OK)
  {
    Error_Handler();
  }
  sMasterConfig.MasterOutputTrigger = TIM_TRGO_RESET;
  sMasterConfig.MasterSlaveMode = TIM_MASTERSLAVEMODE_DISABLE;
  if (HAL_TIMEx_MasterConfigSynchronization(&htim3, &sMasterConfig) != HAL_OK)
  {
    Error_Handler();
  }
  /* USER CODE BEGIN TIM3_Init 2 */

  /* USER CODE END TIM3_Init 2 */

}

/**
  * @brief GPIO Initialization Function
  * @param None
  * @retval None
  */
static void MX_GPIO_Init(void)
{
  GPIO_InitTypeDef GPIO_InitStruct = {0};
  /* USER CODE BEGIN MX_GPIO_Init_1 */

  /* USER CODE END MX_GPIO_Init_1 */

  /* GPIO Ports Clock Enable */
  __HAL_RCC_GPIOH_CLK_ENABLE();
  __HAL_RCC_GPIOA_CLK_ENABLE();
  __HAL_RCC_GPIOE_CLK_ENABLE();

  /*Configure GPIO pin Output Level */
  HAL_GPIO_WritePin(GPIOA, GPIO_PIN_0, GPIO_PIN_RESET);

  /*Configure GPIO pin : PA0 */
  GPIO_InitStruct.Pin = GPIO_PIN_0;
  GPIO_InitStruct.Mode = GPIO_MODE_OUTPUT_PP;
  GPIO_InitStruct.Pull = GPIO_NOPULL;
  GPIO_InitStruct.Speed = GPIO_SPEED_FREQ_LOW;
  HAL_GPIO_Init(GPIOA, &GPIO_InitStruct);

  /*AnalogSwitch Config */
  HAL_SYSCFG_AnalogSwitchConfig(SYSCFG_SWITCH_PA0, SYSCFG_SWITCH_PA0_CLOSE);

  /* USER CODE BEGIN MX_GPIO_Init_2 */

  /* USER CODE END MX_GPIO_Init_2 */
}

/* USER CODE BEGIN 4 */

/* USER CODE END 4 */

 /* MPU Configuration */

void MPU_Config(void)
{
  MPU_Region_InitTypeDef MPU_InitStruct = {0};

  /* Disables the MPU */
  HAL_MPU_Disable();

  /** Initializes and configures the Region and the memory to be protected
  */
  MPU_InitStruct.Enable = MPU_REGION_ENABLE;
  MPU_InitStruct.Number = MPU_REGION_NUMBER0;
  MPU_InitStruct.BaseAddress = 0x0;
  MPU_InitStruct.Size = MPU_REGION_SIZE_4GB;
  MPU_InitStruct.SubRegionDisable = 0x87;
  MPU_InitStruct.TypeExtField = MPU_TEX_LEVEL0;
  MPU_InitStruct.AccessPermission = MPU_REGION_NO_ACCESS;
  MPU_InitStruct.DisableExec = MPU_INSTRUCTION_ACCESS_DISABLE;
  MPU_InitStruct.IsShareable = MPU_ACCESS_SHAREABLE;
  MPU_InitStruct.IsCacheable = MPU_ACCESS_NOT_CACHEABLE;
  MPU_InitStruct.IsBufferable = MPU_ACCESS_NOT_BUFFERABLE;

  HAL_MPU_ConfigRegion(&MPU_InitStruct);
  /* Enables the MPU */
  HAL_MPU_Enable(MPU_PRIVILEGED_DEFAULT);

}

/**
  * @brief  This function is executed in case of error occurrence.
  * @retval None
  */
void Error_Handler(void)
{
  /* USER CODE BEGIN Error_Handler_Debug */
    /* User can add his own implementation to report the HAL error return state */
    __disable_irq();
    while (1)
    {
    }
  /* USER CODE END Error_Handler_Debug */
}

#ifdef  USE_FULL_ASSERT
/**
  * @brief  Reports the name of the source file and the source line number
  *         where the assert_param error has occurred.
  * @param  file: pointer to the source file name
  * @param  line: assert_param error line source number
  * @retval None
  */
void assert_failed(uint8_t *file, uint32_t line)
{
  /* USER CODE BEGIN 6 */
    /* User can add his own implementation to report the file name and line number,
       ex: printf("Wrong parameters value: file %s on line %d\r\n", file, line) */
  /* USER CODE END 6 */
}
#endif /* USE_FULL_ASSERT */

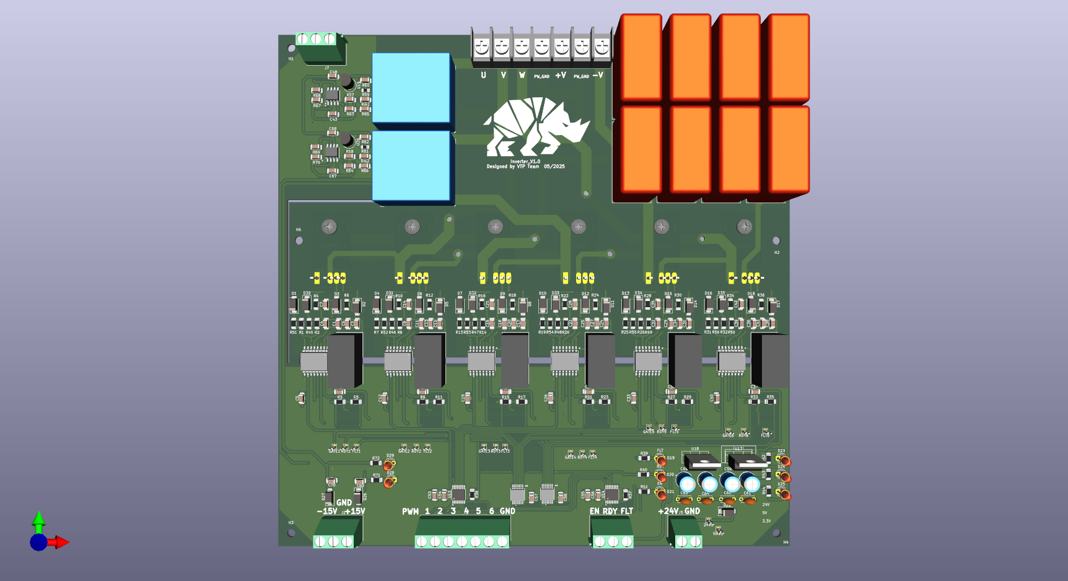
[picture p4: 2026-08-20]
Schematic_Inverter_test/Inverter_test.png

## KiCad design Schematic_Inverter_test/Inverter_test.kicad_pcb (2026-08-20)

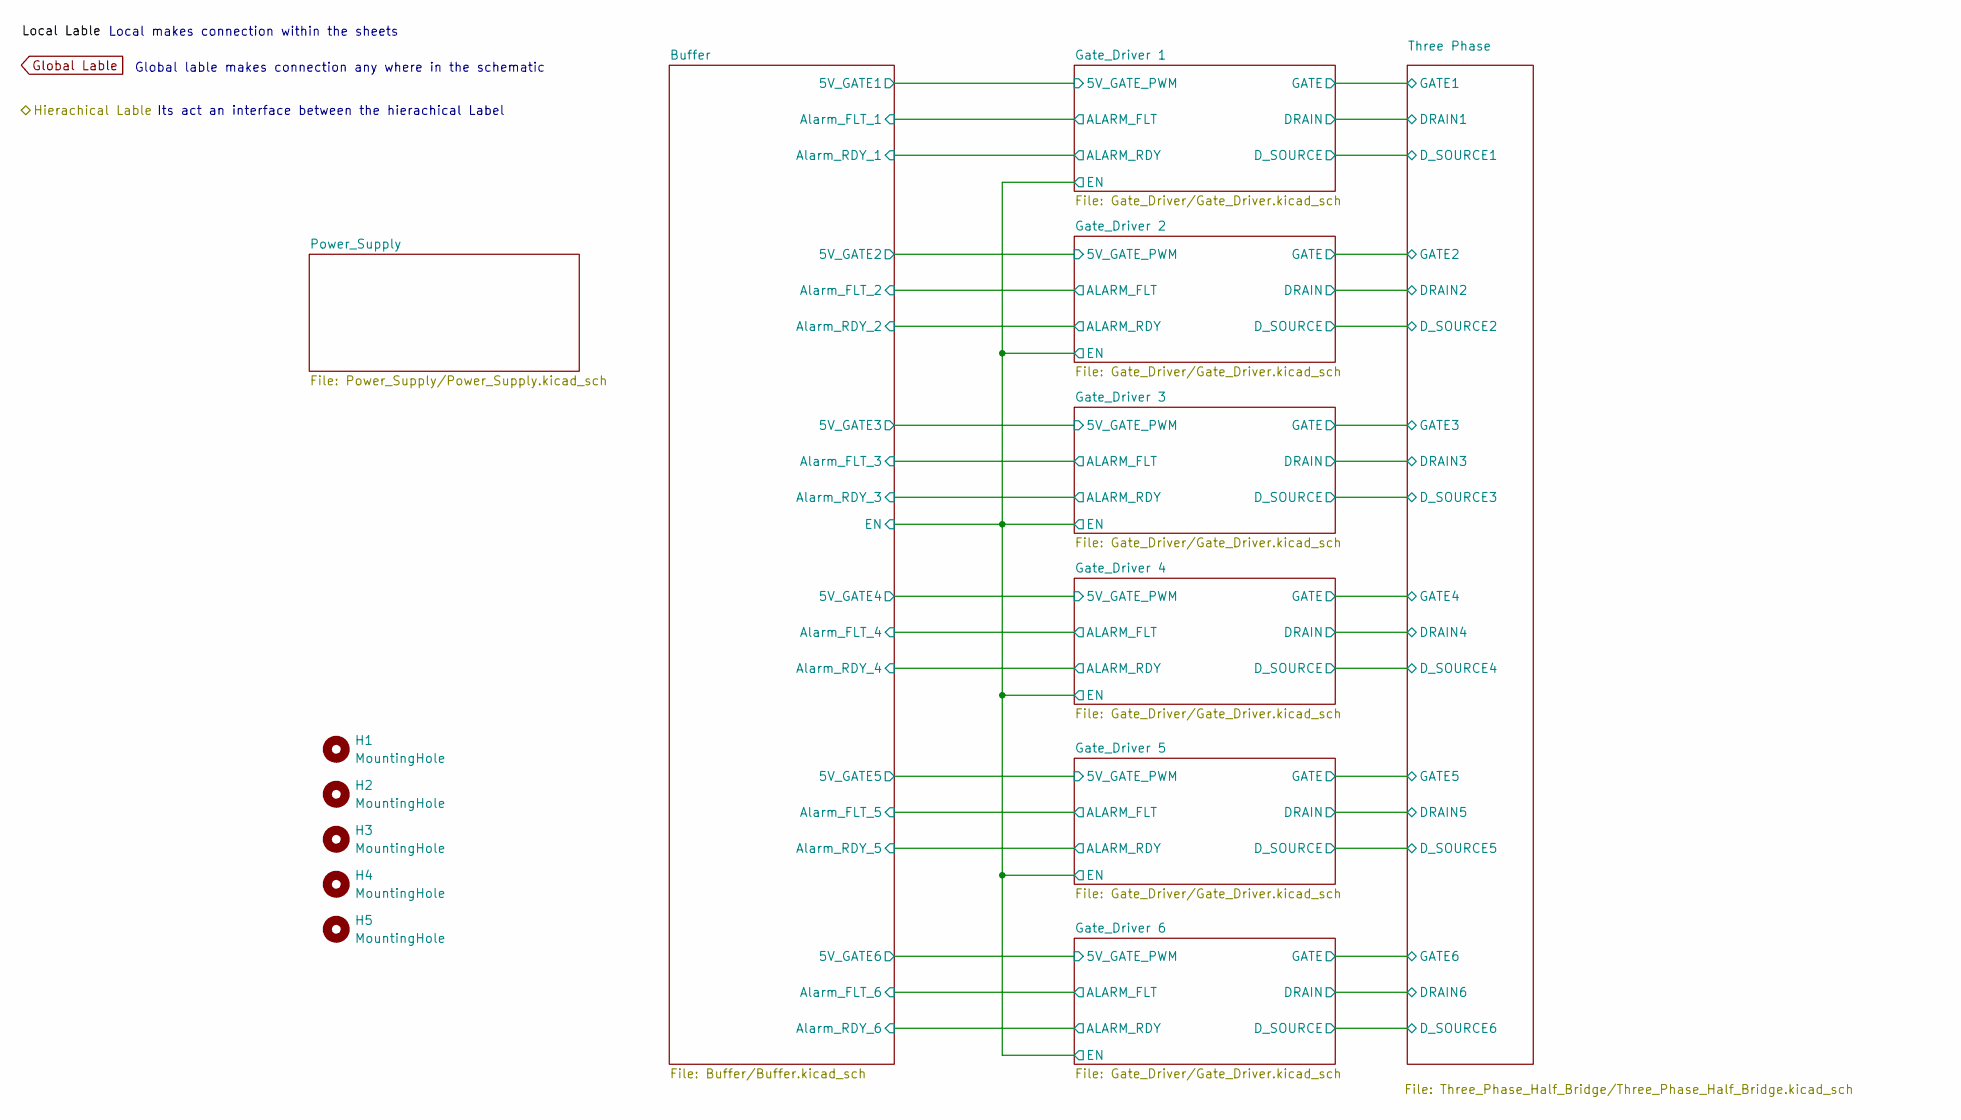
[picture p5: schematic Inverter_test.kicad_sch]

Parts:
H1, H2, H3, H4, H5: MountingHole; MountingHole_3.2mm_M3

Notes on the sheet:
Its act an interface between the hierachical Label
Global lable makes connection any where in the schematic
Local makes connection within the sheets

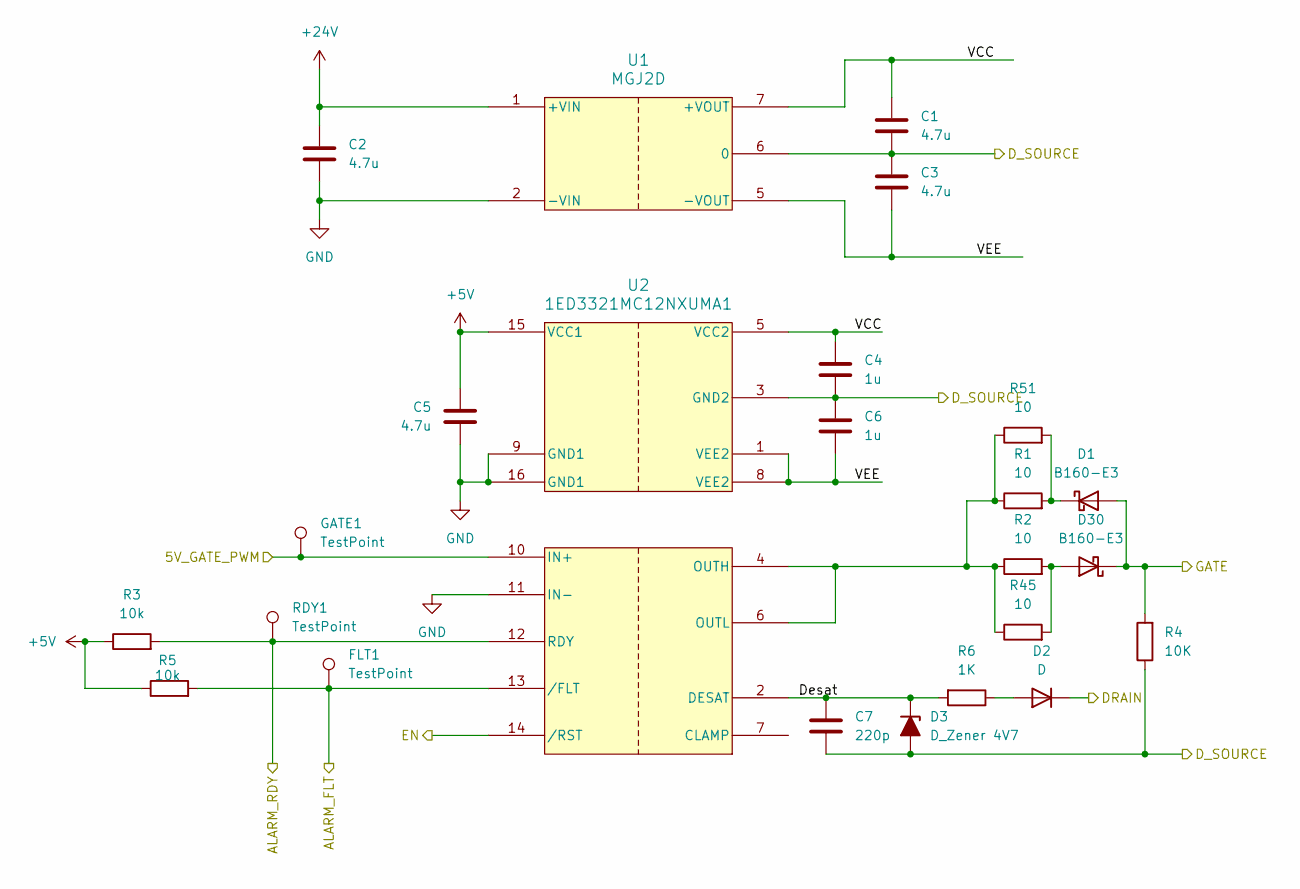
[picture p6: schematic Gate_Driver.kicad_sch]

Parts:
C1, C2, C3, C5: 4.7u; C_1206_3216Metric_Pad1.33x1.80mm_HandSolder
C4, C6: 1u; C_1206_3216Metric_Pad1.33x1.80mm_HandSolder
C7: 220p; C_1206_3216Metric_Pad1.33x1.80mm_HandSolder
D1, D30: B160-E3; D_SMA
D2: D; D_SMA
D3: D_Zener 4V7; D_SMA
FLT1: TestPoint; Pin_D0.7mm_L6.5mm_W1.8mm_FlatFork
GATE1: TestPoint; Pin_D0.7mm_L6.5mm_W1.8mm_FlatFork
R1, R2, R45, R51: 10; R_1206_3216Metric_Pad1.30x1.75mm_HandSolder
R3, R5: 10k; R_1206_3216Metric_Pad1.30x1.75mm_HandSolder
R4: 10K; R_1206_3216Metric_Pad1.30x1.75mm_HandSolder
R6: 1K; R_1206_3216Metric_Pad1.30x1.75mm_HandSolder
RDY1: TestPoint; Pin_D0.7mm_L6.5mm_W1.8mm_FlatFork
U1: MGJ2D; MGJ2_MUR
U2: 1ED3321MC12NXUMA1; PG-DSO-16-40_INF-M

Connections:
+5V: C5.1, R3.1, R5.1, U2.15 (VCC1); also elsewhere on the board
+24V: C2.1, U1.1 (+VIN); also elsewhere on the board
/Buffer/5V_DRIVER_EN: U2.14 (/RST); also elsewhere on the board
/Buffer/5V_GATE1: GATE1.1, U2.10 (IN+); also elsewhere on the board
/Buffer/Alarm_FLT_1: FLT1.1, R5.2, U2.13 (/FLT); also elsewhere on the board
/Buffer/Alarm_RDY_1: R3.2, RDY1.1, U2.12 (RDY); also elsewhere on the board
/Gate_Driver 1/D_SOURCE: C1.2, C3.2, C4.2, C6.1, C7.2, D3.2 (A), R4.1, U1.6 (0), U2.3 (GND2); also elsewhere on the board
/Gate_Driver 1/Desat: C7.1, D3.1 (K), R6.2, U2.2 (DESAT)
/Gate_Driver 1/GATE: D1.2 (A), D30.1 (K), R4.2; also elsewhere on the board
/Gate_Driver 1/VCC: C1.1, C4.1, U1.7 (+VOUT), U2.5 (VCC2)
/Gate_Driver 1/VEE: C3.1, C6.2, U1.5 (-VOUT), U2.1 (VEE2), U2.8 (VEE2)
/Three Phase/+270V: D2.1 (K); also elsewhere on the board
GND: C2.2, C5.2, U1.2 (-VIN), U2.9 (GND1), U2.11 (IN-), U2.16 (GND1); also elsewhere on the board
unnamed: D1.1 (K), R1.2, R51.2
unnamed: D2.2 (A), R6.1
unnamed: D30.2 (A), R2.2, R45.2
unnamed: R1.1, R2.1, R45.1, R51.1, U2.4 (OUTH), U2.6 (OUTL)

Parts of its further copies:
C8, C9, C10, C12, C15, C16, C17, C19, C22, C23, C24, C26, C29, C30, C31, C33, C36, C37, C38, C40: 4.7u; C_1206_3216Metric_Pad1.33x1.80mm_HandSolder
C11, C13, C18, C20, C25, C27, C32, C34, C39, C41: 1u; C_1206_3216Metric_Pad1.33x1.80mm_HandSolder
C14, C21, C28, C35, C42: 220p; C_1206_3216Metric_Pad1.33x1.80mm_HandSolder
D4, D7, D10, D13, D16, D31, D32, D33, D34, D35: B160-E3; D_SMA
D5, D8, D11, D14, D17: D; D_SMA
D6, D9, D12, D15, D18: D_Zener 4V7; D_SMA
FLT2, FLT3, FLT4, FLT5, FLT6: TestPoint; Pin_D0.7mm_L6.5mm_W1.8mm_FlatFork
GATE2, GATE3, GATE4, GATE5, GATE6: TestPoint; Pin_D0.7mm_L6.5mm_W1.8mm_FlatFork
R7, R8, R13, R14, R19, R20, R25, R26, R31, R32, R46, R47, R48, R49, R50, R52, R53, R54, R55, R56: 10; R_1206_3216Metric_Pad1.30x1.75mm_HandSolder
R9, R11, R15, R17, R21, R23, R27, R29, R33, R35: 10k; R_1206_3216Metric_Pad1.30x1.75mm_HandSolder
R10, R16, R22, R28, R34: 10K; R_1206_3216Metric_Pad1.30x1.75mm_HandSolder
R12, R18, R24, R30, R36: 1K; R_1206_3216Metric_Pad1.30x1.75mm_HandSolder
RDY2, RDY3, RDY4, RDY5, RDY6: TestPoint; Pin_D0.7mm_L6.5mm_W1.8mm_FlatFork
U3, U5, U7, U9, U11: MGJ2D; MGJ2_MUR
U4, U6, U8, U10, U12: 1ED3321MC12NXUMA1; PG-DSO-16-40_INF-M

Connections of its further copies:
+5V: C12.1, C19.1, C26.1, C33.1, C40.1, R9.1, R11.1, R15.1, R17.1, R21.1, R23.1, R27.1, R29.1, R33.1, R35.1, U4.15 (VCC1), U6.15 (VCC1), U8.15 (VCC1), U10.15 (VCC1), U12.15 (VCC1); also elsewhere on the board
+24V: C9.1, C16.1, C23.1, C30.1, C37.1, U3.1 (+VIN), U5.1 (+VIN), U7.1 (+VIN), U9.1 (+VIN), U11.1 (+VIN); also elsewhere on the board
/Buffer/5V_DRIVER_EN: U4.14 (/RST), U6.14 (/RST), U8.14 (/RST), U10.14 (/RST), U12.14 (/RST); also elsewhere on the board
/Buffer/5V_GATE2: GATE2.1, U4.10 (IN+); also elsewhere on the board
/Buffer/5V_GATE3: GATE3.1, U6.10 (IN+); also elsewhere on the board
/Buffer/5V_GATE4: GATE4.1, U8.10 (IN+); also elsewhere on the board
/Buffer/5V_GATE5: GATE5.1, U10.10 (IN+); also elsewhere on the board
/Buffer/5V_GATE6: GATE6.1, U12.10 (IN+); also elsewhere on the board
/Buffer/Alarm_FLT_2: FLT2.1, R11.2, U4.13 (/FLT); also elsewhere on the board
/Buffer/Alarm_FLT_3: FLT3.1, R17.2, U6.13 (/FLT); also elsewhere on the board
/Buffer/Alarm_FLT_4: FLT4.1, R23.2, U8.13 (/FLT); also elsewhere on the board
/Buffer/Alarm_FLT_5: FLT5.1, R29.2, U10.13 (/FLT); also elsewhere on the board
/Buffer/Alarm_FLT_6: FLT6.1, R35.2, U12.13 (/FLT); also elsewhere on the board
/Buffer/Alarm_RDY_2: R9.2, RDY2.1, U4.12 (RDY); also elsewhere on the board
/Buffer/Alarm_RDY_3: R15.2, RDY3.1, U6.12 (RDY); also elsewhere on the board
/Buffer/Alarm_RDY_4: R21.2, RDY4.1, U8.12 (RDY); also elsewhere on the board
/Buffer/Alarm_RDY_5: R27.2, RDY5.1, U10.12 (RDY); also elsewhere on the board
/Buffer/Alarm_RDY_6: R33.2, RDY6.1, U12.12 (RDY); also elsewhere on the board
/Gate_Driver 2/D_SOURCE: C8.2, C10.2, C11.2, C13.1, C14.2, D6.2 (A), R10.1, U3.6 (0), U4.3 (GND2); also elsewhere on the board
/Gate_Driver 2/Desat: C14.1, D6.1 (K), R12.2, U4.2 (DESAT)
/Gate_Driver 2/GATE: D4.2 (A), D31.1 (K), R10.2; also elsewhere on the board
/Gate_Driver 2/VCC: C8.1, C11.1, U3.7 (+VOUT), U4.5 (VCC2)
/Gate_Driver 2/VEE: C10.1, C13.2, U3.5 (-VOUT), U4.1 (VEE2), U4.8 (VEE2)
/Gate_Driver 3/D_SOURCE: C15.2, C17.2, C18.2, C20.1, C21.2, D9.2 (A), R16.1, U5.6 (0), U6.3 (GND2); also elsewhere on the board
/Gate_Driver 3/Desat: C21.1, D9.1 (K), R18.2, U6.2 (DESAT)
/Gate_Driver 3/GATE: D7.2 (A), D32.1 (K), R16.2; also elsewhere on the board
/Gate_Driver 3/VCC: C15.1, C18.1, U5.7 (+VOUT), U6.5 (VCC2)
/Gate_Driver 3/VEE: C17.1, C20.2, U5.5 (-VOUT), U6.1 (VEE2), U6.8 (VEE2)
/Gate_Driver 4/D_SOURCE: C22.2, C24.2, C25.2, C27.1, C28.2, D12.2 (A), R22.1, U7.6 (0), U8.3 (GND2); also elsewhere on the board
/Gate_Driver 4/Desat: C28.1, D12.1 (K), R24.2, U8.2 (DESAT)
/Gate_Driver 4/GATE: D10.2 (A), D33.1 (K), R22.2; also elsewhere on the board
/Gate_Driver 4/VCC: C22.1, C25.1, U7.7 (+VOUT), U8.5 (VCC2)
/Gate_Driver 4/VEE: C24.1, C27.2, U7.5 (-VOUT), U8.1 (VEE2), U8.8 (VEE2)
/Gate_Driver 5/D_SOURCE: C29.2, C31.2, C32.2, C34.1, C35.2, D15.2 (A), R28.1, U9.6 (0), U10.3 (GND2); also elsewhere on the board
/Gate_Driver 5/Desat: C35.1, D15.1 (K), R30.2, U10.2 (DESAT)
/Gate_Driver 5/GATE: D13.2 (A), D34.1 (K), R28.2; also elsewhere on the board
/Gate_Driver 5/VCC: C29.1, C32.1, U9.7 (+VOUT), U10.5 (VCC2)
/Gate_Driver 5/VEE: C31.1, C34.2, U9.5 (-VOUT), U10.1 (VEE2), U10.8 (VEE2)
/Gate_Driver 6/D_SOURCE: C36.2, C38.2, C39.2, C41.1, C42.2, D18.2 (A), R34.1, U11.6 (0), U12.3 (GND2); also elsewhere on the board
/Gate_Driver 6/Desat: C42.1, D18.1 (K), R36.2, U12.2 (DESAT)
/Gate_Driver 6/GATE: D16.2 (A), D35.1 (K), R34.2; also elsewhere on the board
/Gate_Driver 6/VCC: C36.1, C39.1, U11.7 (+VOUT), U12.5 (VCC2)
/Gate_Driver 6/VEE: C38.1, C41.2, U11.5 (-VOUT), U12.1 (VEE2), U12.8 (VEE2)
/Three Phase/+270V: D8.1 (K), D14.1 (K); also elsewhere on the board
/Three Phase/U: D5.1 (K); also elsewhere on the board
/Three Phase/V: D11.1 (K); also elsewhere on the board
/Three Phase/W: D17.1 (K); also elsewhere on the board
GND: C9.2, C12.2, C16.2, C19.2, C23.2, C26.2, C30.2, C33.2, C37.2, C40.2, U3.2 (-VIN), U4.9 (GND1), U4.11 (IN-), U4.16 (GND1), U5.2 (-VIN), U6.9 (GND1), U6.11 (IN-), U6.16 (GND1), U7.2 (-VIN), U8.9 (GND1), U8.11 (IN-), U8.16 (GND1), U9.2 (-VIN), U10.9 (GND1), U10.11 (IN-), U10.16 (GND1), U11.2 (-VIN), U12.9 (GND1), U12.11 (IN-), U12.16 (GND1); also elsewhere on the board
unnamed: D4.1 (K), R7.2, R52.2
unnamed: D5.2 (A), R12.1
unnamed: D7.1 (K), R13.2, R53.2
unnamed: D8.2 (A), R18.1
unnamed: D10.1 (K), R19.2, R54.2
unnamed: D11.2 (A), R24.1
unnamed: D13.1 (K), R25.2, R55.2
unnamed: D14.2 (A), R30.1
unnamed: D16.1 (K), R31.2, R56.2
unnamed: D17.2 (A), R36.1
unnamed: D31.2 (A), R8.2, R46.2
unnamed: D32.2 (A), R14.2, R47.2
unnamed: D33.2 (A), R20.2, R48.2
unnamed: D34.2 (A), R26.2, R49.2
unnamed: D35.2 (A), R32.2, R50.2
unnamed: R7.1, R8.1, R46.1, R52.1, U4.4 (OUTH), U4.6 (OUTL)
unnamed: R13.1, R14.1, R47.1, R53.1, U6.4 (OUTH), U6.6 (OUTL)
unnamed: R19.1, R20.1, R48.1, R54.1, U8.4 (OUTH), U8.6 (OUTL)
unnamed: R25.1, R26.1, R49.1, R55.1, U10.4 (OUTH), U10.6 (OUTL)
unnamed: R31.1, R32.1, R50.1, R56.1, U12.4 (OUTH), U12.6 (OUTL)

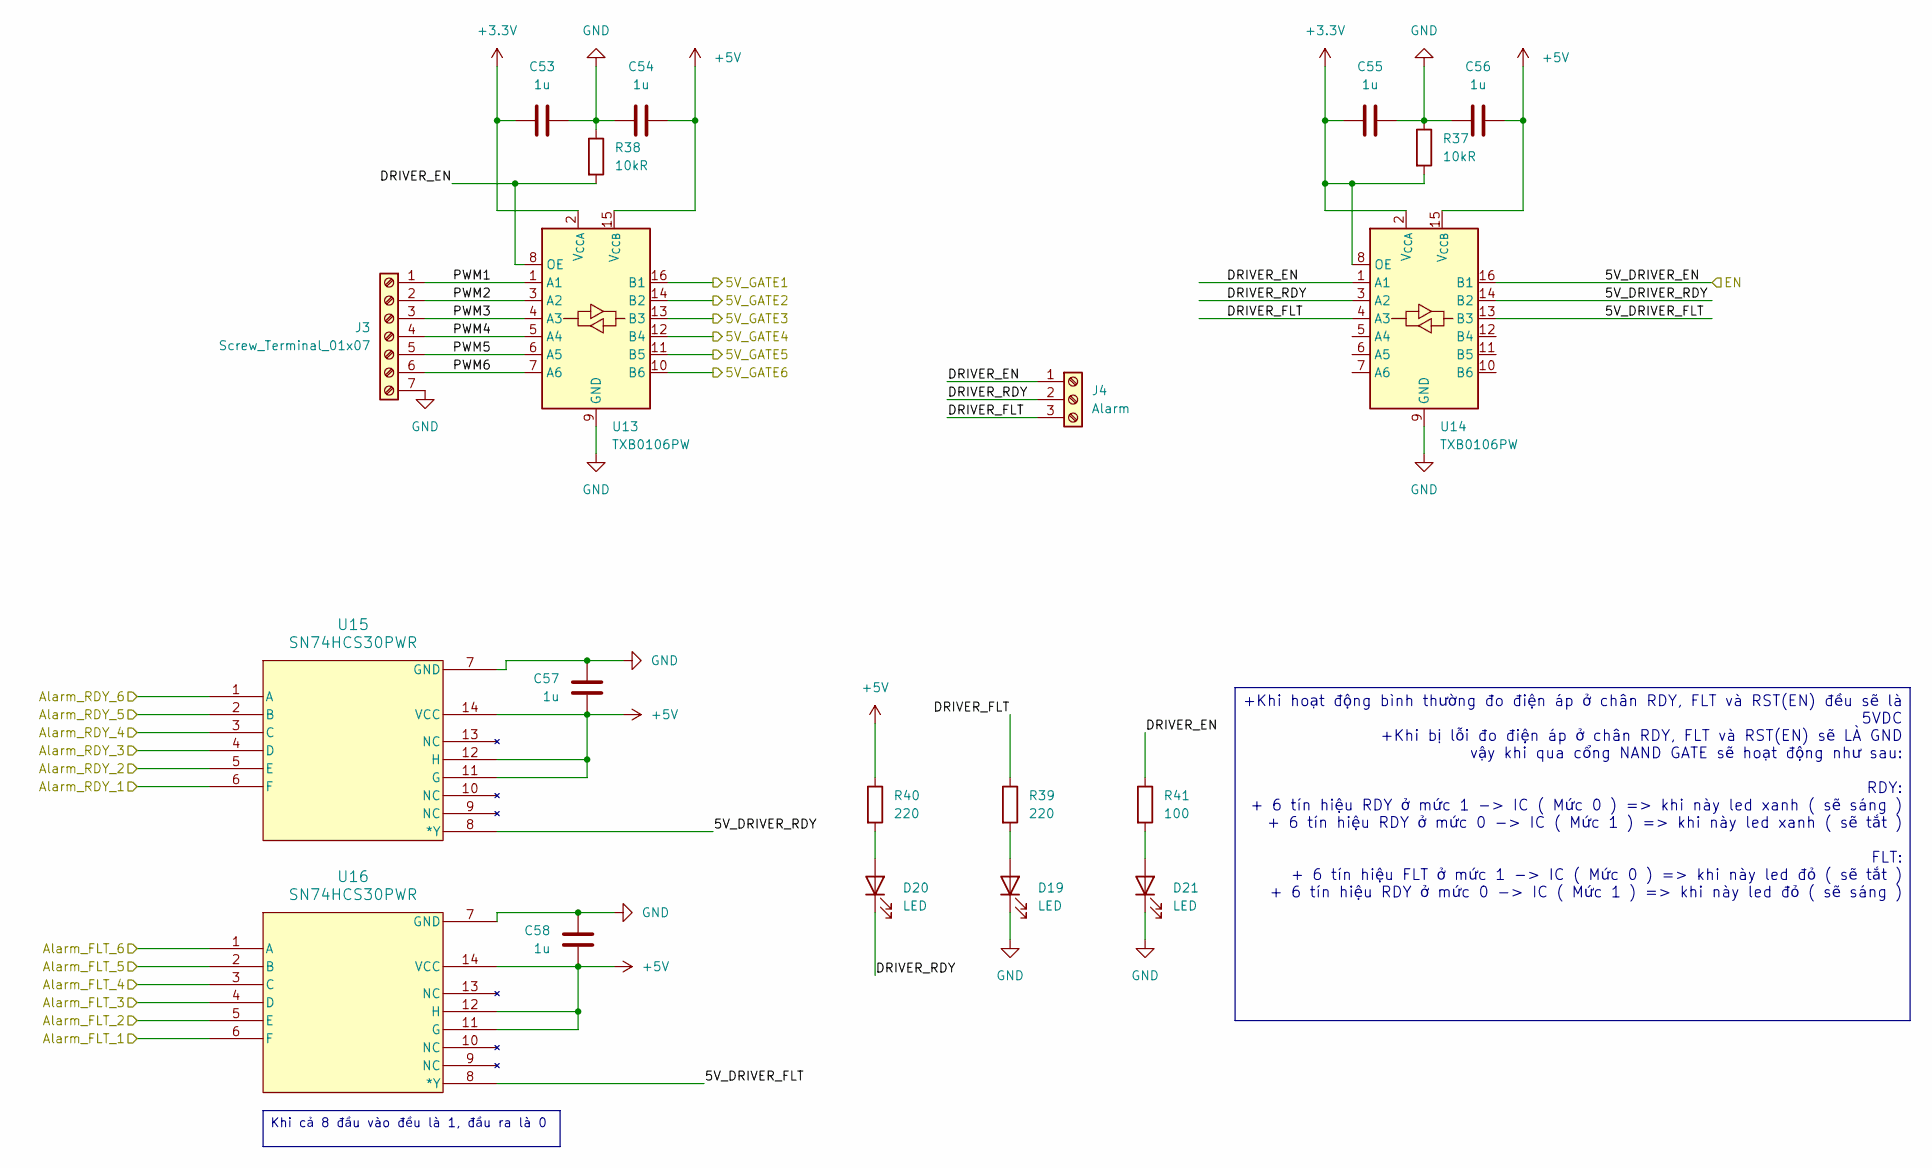
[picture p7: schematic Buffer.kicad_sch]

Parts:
C53, C54, C55, C56, C57, C58: 1u; C_1206_3216Metric_Pad1.33x1.80mm_HandSolder
D19, D20, D21: LED; LED_D3.0mm
J3: Screw_Terminal_01x07; TerminalBlock_Phoenix_MKDS-1,5-7_1x07_P5.00mm_Horizontal
J4: Alarm; TerminalBlock_Phoenix_MKDS-1,5-3_1x03_P5.00mm_Horizontal
R37, R38: 10kR; R_1206_3216Metric_Pad1.30x1.75mm_HandSolder
R39, R40: 220; R_1206_3216Metric_Pad1.30x1.75mm_HandSolder
R41: 100; R_1206_3216Metric_Pad1.30x1.75mm_HandSolder
U13, U14: TXB0106PW; TSSOP-16_4.4x5mm_P0.65mm
U15, U16: SN74HCS30PWR; SOIC-14_SN74HCS30PWR-M

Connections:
+3.3V: C53.2, C55.2, R37.2, U13.2 (V_{CCA}), U14.2 (V_{CCA}), U14.8 (OE); also elsewhere on the board
+5V: C54.1, C56.1, C57.2, C58.2, R40.1, U13.15 (V_{CCB}), U14.15 (V_{CCB}), U15.11 (G), U15.12 (H), U15.14 (VCC), U16.11 (G), U16.12 (H), U16.14 (VCC); also elsewhere on the board
/Buffer/5V_DRIVER_EN: U14.16 (B1); also elsewhere on the board
/Buffer/5V_DRIVER_FLT: U14.13 (B3), U16.8 (*Y)
/Buffer/5V_DRIVER_RDY: U14.14 (B2), U15.8 (*Y)
/Buffer/5V_GATE1: U13.16 (B1); also elsewhere on the board
/Buffer/5V_GATE2: U13.14 (B2); also elsewhere on the board
/Buffer/5V_GATE3: U13.13 (B3); also elsewhere on the board
/Buffer/5V_GATE4: U13.12 (B4); also elsewhere on the board
/Buffer/5V_GATE5: U13.11 (B5); also elsewhere on the board
/Buffer/5V_GATE6: U13.10 (B6); also elsewhere on the board
/Buffer/Alarm_FLT_1: U16.6 (F); also elsewhere on the board
/Buffer/Alarm_FLT_2: U16.5 (E); also elsewhere on the board
/Buffer/Alarm_FLT_3: U16.4 (D); also elsewhere on the board
/Buffer/Alarm_FLT_4: U16.3 (C); also elsewhere on the board
/Buffer/Alarm_FLT_5: U16.2 (B); also elsewhere on the board
/Buffer/Alarm_FLT_6: U16.1 (A); also elsewhere on the board
/Buffer/Alarm_RDY_1: U15.6 (F); also elsewhere on the board
/Buffer/Alarm_RDY_2: U15.5 (E); also elsewhere on the board
/Buffer/Alarm_RDY_3: U15.4 (D); also elsewhere on the board
/Buffer/Alarm_RDY_4: U15.3 (C); also elsewhere on the board
/Buffer/Alarm_RDY_5: U15.2 (B); also elsewhere on the board
/Buffer/Alarm_RDY_6: U15.1 (A); also elsewhere on the board
/Buffer/DRIVER_EN: J4.1, R38.2, R41.1, U13.8 (OE), U14.1 (A1)
/Buffer/DRIVER_FLT: J4.3, R39.1, U14.4 (A3)
/Buffer/DRIVER_RDY: D20.1 (K), J4.2, U14.3 (A2)
/Buffer/PWM1: J3.1, U13.1 (A1)
/Buffer/PWM2: J3.2, U13.3 (A2)
/Buffer/PWM3: J3.3, U13.4 (A3)
/Buffer/PWM4: J3.4, U13.5 (A4)
/Buffer/PWM5: J3.5, U13.6 (A5)
/Buffer/PWM6: J3.6, U13.7 (A6)
GND: C53.1, C54.2, C55.1, C56.2, C57.1, C58.1, D19.1 (K), D21.1 (K), J3.7, R37.1, R38.1, U13.9 (GND), U14.9 (GND), U15.7 (GND), U16.7 (GND); also elsewhere on the board
unnamed: D19.2 (A), R39.2
unnamed: D20.2 (A), R40.2
unnamed: D21.2 (A), R41.2

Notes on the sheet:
+Khi hoạt động bình thường đo điện áp ở chân RDY, FLT và RST(EN) đều sẽ là 5VDC +Khi bị lỗi đo điện áp ở chân RDY, FLT và RST(EN) sẽ LÀ GND vậy khi qua cổng NAND GATE sẽ hoạt động như sau: RDY: + 6 tín hiệu RDY ở mức 1 -> IC ( Mức 0 ) => khi này led xanh ( sẽ sáng ) + 6 tín hiệu RDY ở mức 0 -> IC (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
Khi cả 8 đầu vào đều là 1, đầu ra là 0

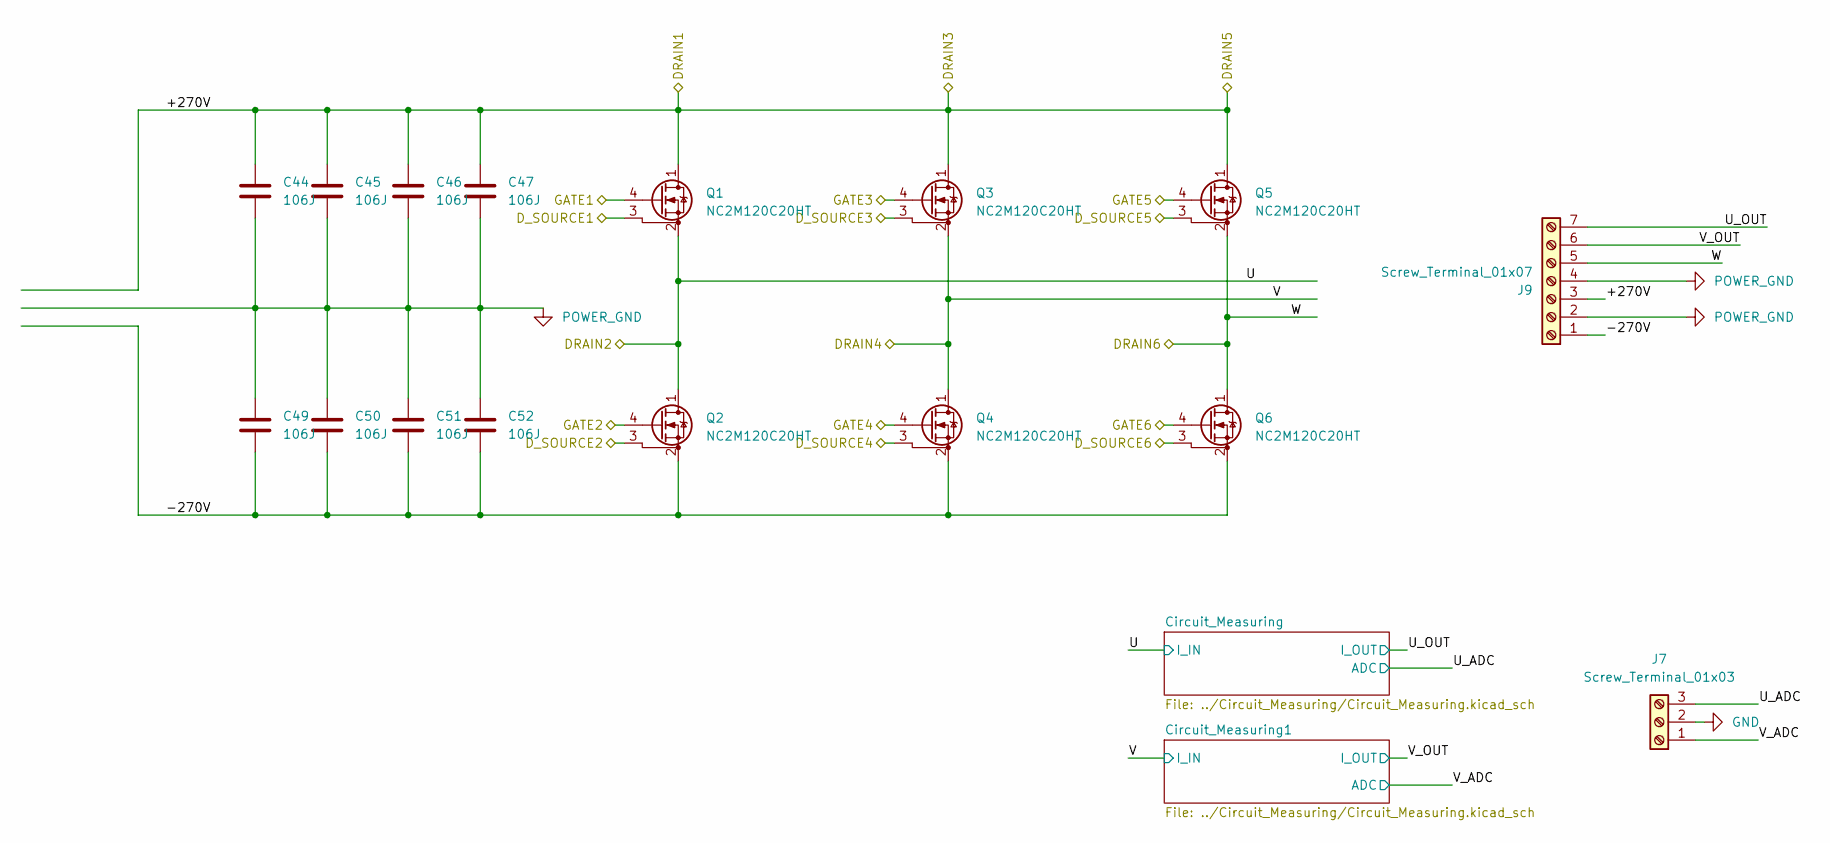
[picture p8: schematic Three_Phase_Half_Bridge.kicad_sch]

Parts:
C44, C45, C46, C47, C49, C50, C51, C52: 106J; C_Rect_L31.5mm_W15.0mm_P27.50mm_MKS4
J7: Screw_Terminal_01x03; TerminalBlock_Phoenix_MKDS-1,5-3_1x03_P5.00mm_Horizontal
J9: Screw_Terminal_01x07; Untitled
Q1, Q2, Q3, Q4, Q5, Q6: NC2M120C20HT; TO-247-4_Horizontal_TabUp

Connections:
/Gate_Driver 1/D_SOURCE: Q1.3 (DS); also elsewhere on the board
/Gate_Driver 1/GATE: Q1.4 (G); also elsewhere on the board
/Gate_Driver 2/D_SOURCE: Q2.3 (DS); also elsewhere on the board
/Gate_Driver 2/GATE: Q2.4 (G); also elsewhere on the board
/Gate_Driver 3/D_SOURCE: Q3.3 (DS); also elsewhere on the board
/Gate_Driver 3/GATE: Q3.4 (G); also elsewhere on the board
/Gate_Driver 4/D_SOURCE: Q4.3 (DS); also elsewhere on the board
/Gate_Driver 4/GATE: Q4.4 (G); also elsewhere on the board
/Gate_Driver 5/D_SOURCE: Q5.3 (DS); also elsewhere on the board
/Gate_Driver 5/GATE: Q5.4 (G); also elsewhere on the board
/Gate_Driver 6/D_SOURCE: Q6.3 (DS); also elsewhere on the board
/Gate_Driver 6/GATE: Q6.4 (G); also elsewhere on the board
/Three Phase/+270V: C44.1, C45.1, C46.1, C47.1, J9.3, Q1.1 (D), Q3.1 (D), Q5.1 (D); also elsewhere on the board
/Three Phase/-270V: C49.2, C50.2, C51.2, C52.2, J9.1, Q2.2 (S), Q4.2 (S), Q6.2 (S)
/Three Phase/U: Q1.2 (S), Q2.1 (D); also elsewhere on the board
/Three Phase/U_ADC: J7.3; also elsewhere on the board
/Three Phase/U_OUT: J9.7; also elsewhere on the board
/Three Phase/V: Q3.2 (S), Q4.1 (D); also elsewhere on the board
/Three Phase/V_ADC: J7.1; also elsewhere on the board
/Three Phase/V_OUT: J9.6; also elsewhere on the board
/Three Phase/W: J9.5, Q5.2 (S), Q6.1 (D); also elsewhere on the board
GND: J7.2; also elsewhere on the board
POWER_GND: C44.2, C45.2, C46.2, C47.2, C49.1, C50.1, C51.1, C52.1, J9.2, J9.4

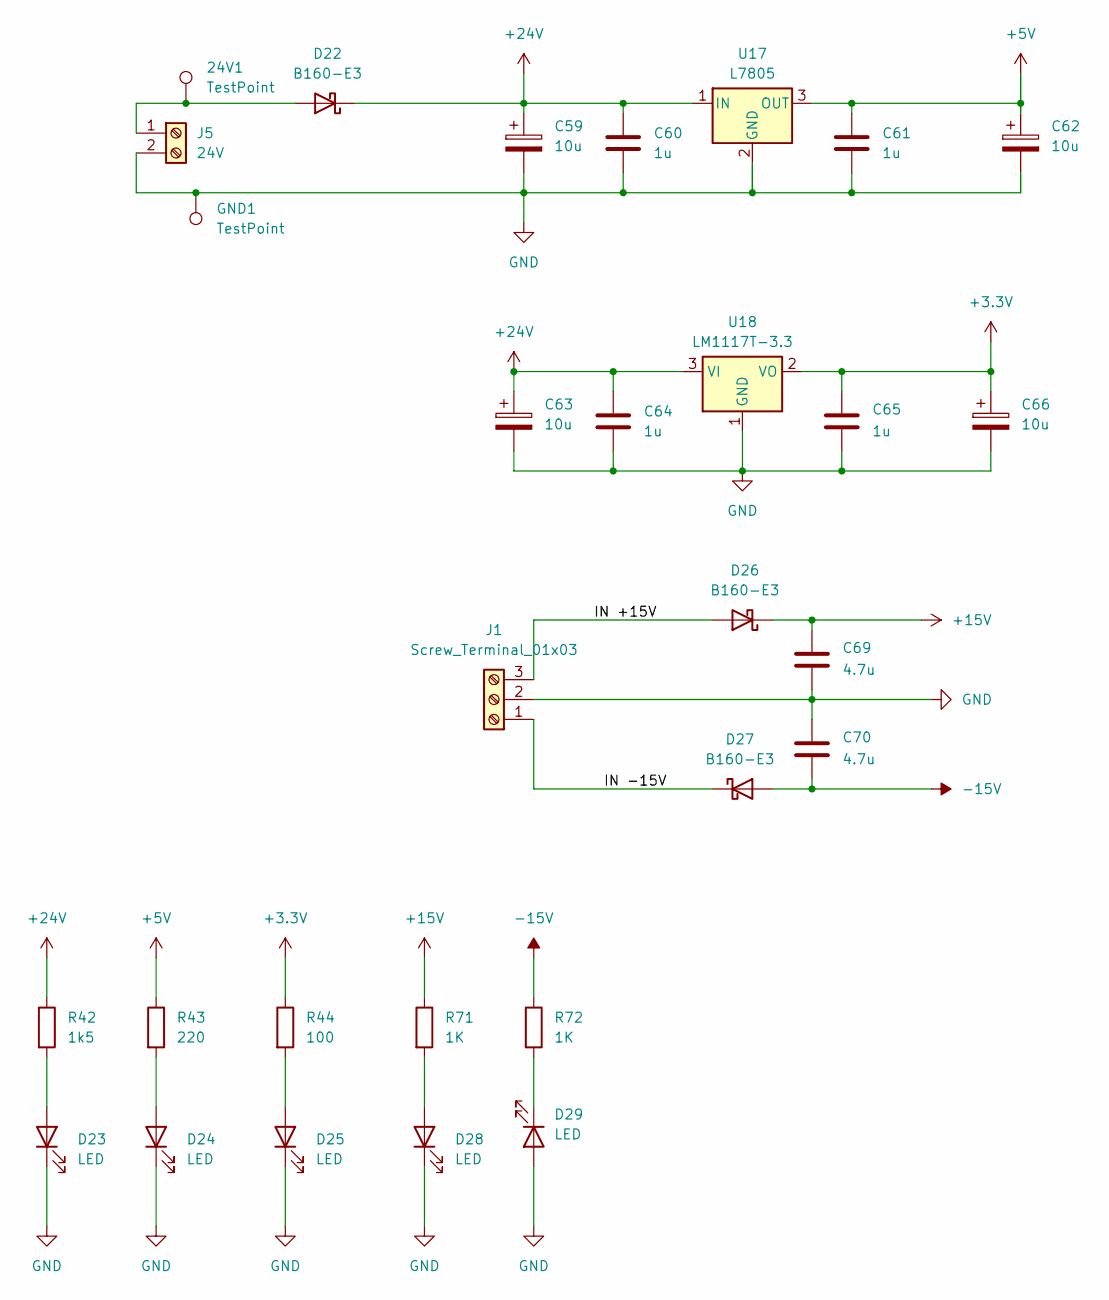
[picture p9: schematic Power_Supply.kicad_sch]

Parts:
24V1: TestPoint; Pin_D0.7mm_L6.5mm_W1.8mm_FlatFork
C59, C62, C63, C66: 10u; CP_Radial_D6.3mm_P2.50mm
C60, C61, C64, C65: 1u; C_Disc_D5.0mm_W2.5mm_P5.00mm
C69, C70: 4.7u; C_1206_3216Metric_Pad1.33x1.80mm_HandSolder
D22, D26, D27: B160-E3; D_SMA
D23, D24, D25, D28, D29: LED; LED_D3.0mm
GND1: TestPoint; Pin_D0.7mm_L6.5mm_W1.8mm_FlatFork
J1: Screw_Terminal_01x03; TerminalBlock_Phoenix_MKDS-1,5-3_1x03_P5.00mm_Horizontal
J5: 24V; TerminalBlock_Phoenix_MKDS-1,5-2_1x02_P5.00mm_Horizontal
R42: 1k5; R_1206_3216Metric_Pad1.30x1.75mm_HandSolder
R43: 220; R_1206_3216Metric_Pad1.30x1.75mm_HandSolder
R44: 100; R_1206_3216Metric_Pad1.30x1.75mm_HandSolder
R71, R72: 1K; R_1206_3216Metric_Pad1.30x1.75mm_HandSolder
U17: L7805; TO-220-3_Vertical
U18: LM1117T-3.3; TO-220-3_Vertical

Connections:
+3.3V: C65.1, C66.1, R44.1, U18.2 (VO); also elsewhere on the board
+5V: C61.1, C62.1, R43.1, U17.3 (OUT); also elsewhere on the board
+15V: C69.1, D26.1 (K), R71.1; also elsewhere on the board
+24V: C59.1, C60.1, C63.1, C64.1, D22.1 (K), R42.1, U17.1 (IN), U18.3 (VI); also elsewhere on the board
-15V: C70.2, D27.2 (A), R72.1; also elsewhere on the board
/Power_Supply/IN +15V: D26.2 (A), J1.3
/Power_Supply/IN -15V: D27.1 (K), J1.1
GND: C59.2, C60.2, C61.2, C62.2, C63.2, C64.2, C65.2, C66.2, C69.2, C70.1, D23.1 (K), D24.1 (K), D25.1 (K), D28.1 (K), D29.2 (A), GND1.1, J1.2, J5.2, U17.2 (GND), U18.1 (GND); also elsewhere on the board
unnamed: 24V1.1, D22.2 (A), J5.1
unnamed: D23.2 (A), R42.2
unnamed: D24.2 (A), R43.2
unnamed: D25.2 (A), R44.2
unnamed: D28.2 (A), R71.2
unnamed: D29.1 (K), R72.2

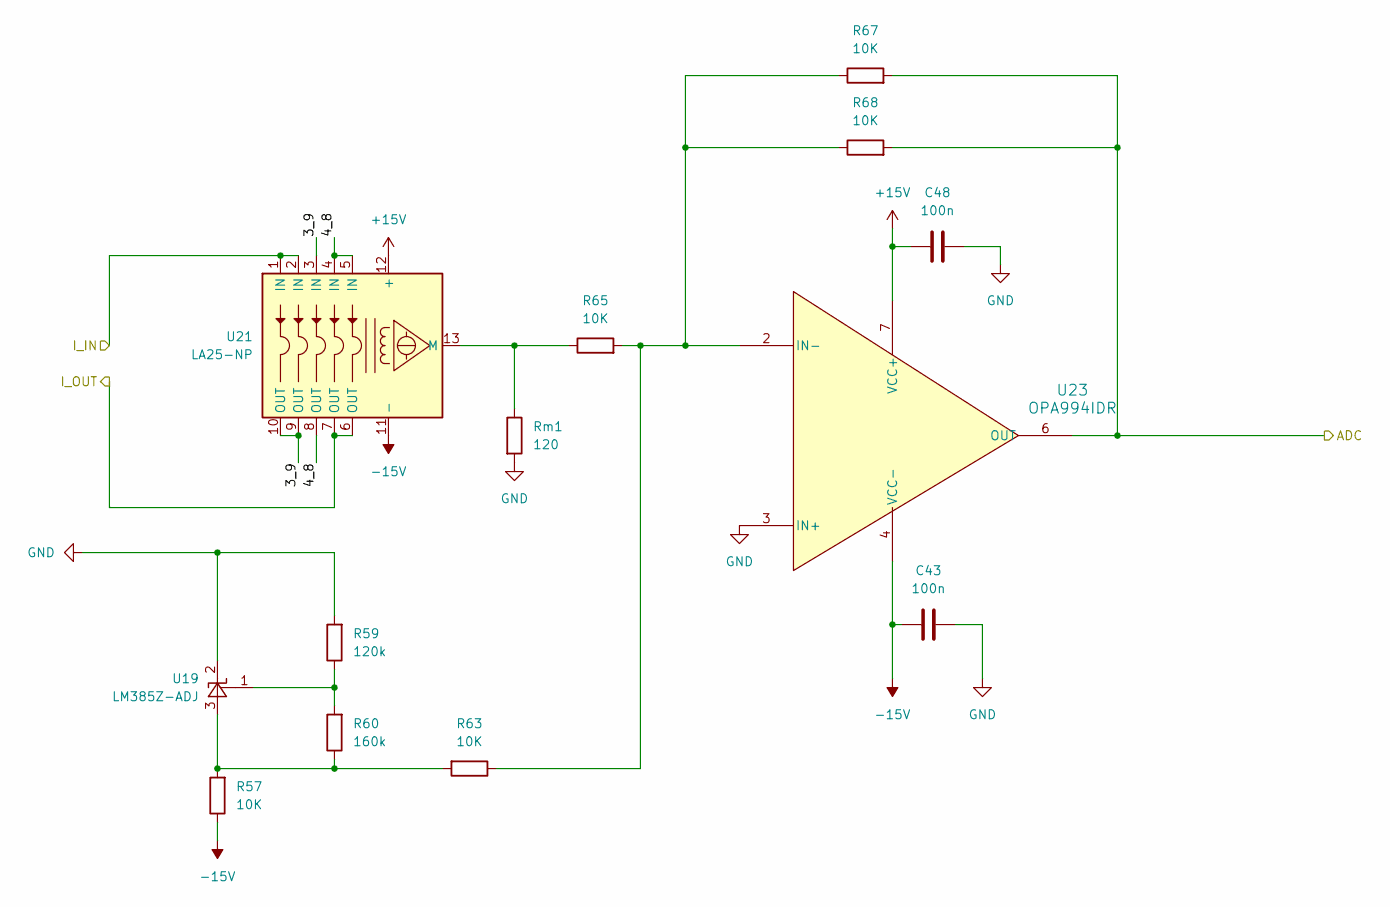
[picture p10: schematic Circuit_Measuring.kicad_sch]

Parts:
C43, C48: 100n; C_1206_3216Metric_Pad1.33x1.80mm_HandSolder
R57, R63, R65, R67, R68: 10K; C_1206_3216Metric_Pad1.33x1.80mm_HandSolder
R59: 120k; R_0805_2012Metric_Pad1.20x1.40mm_HandSolder
R60: 160k; C_1206_3216Metric_Pad1.33x1.80mm_HandSolder
Rm1: 120; C_1206_3216Metric_Pad1.33x1.80mm_HandSolder
U19: LM385Z-ADJ; TO-92_Inline
U21: LA25-NP; LEM_LA25-NP
U23: OPA994IDR; SOIC8_D_TEX

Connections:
+15V: C48.1, U21.12 (+), U23.7 (VCC+); also elsewhere on the board
-15V: C43.2, R57.1, U21.11 (-), U23.4 (VCC-); also elsewhere on the board
/Three Phase/Circuit_Measuring/3_9: U21.3 (IN), U21.9 (OUT), U21.10 (OUT)
/Three Phase/Circuit_Measuring/4_8: U21.4 (IN), U21.5 (IN), U21.8 (OUT)
/Three Phase/U: U21.1 (IN), U21.2 (IN); also elsewhere on the board
/Three Phase/U_ADC: R67.2, R68.2, U23.6 (OUT); also elsewhere on the board
/Three Phase/U_OUT: U21.6 (OUT), U21.7 (OUT); also elsewhere on the board
GND: C43.1, C48.2, R59.2, Rm1.2, U19.2 (K), U23.3 (IN+); also elsewhere on the board
unnamed: R57.2, R60.1, R63.2, U19.3 (A)
unnamed: R59.1, R60.2, U19.1 (FB)
unnamed: R65.1, Rm1.1, U21.13 (M)
unnamed: R63.1, R65.2, R67.1, R68.1, U23.2 (IN-)

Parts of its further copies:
C67, C68: 100n; C_1206_3216Metric_Pad1.33x1.80mm_HandSolder
R58, R64, R66, R69, R70: 10K; C_1206_3216Metric_Pad1.33x1.80mm_HandSolder
R61: 120k; R_0805_2012Metric_Pad1.20x1.40mm_HandSolder
R62: 160k; C_1206_3216Metric_Pad1.33x1.80mm_HandSolder
Rm2: 120; C_1206_3216Metric_Pad1.33x1.80mm_HandSolder
U20: LM385Z-ADJ; TO-92_Inline
U22: LA25-NP; LEM_LA25-NP
U24: OPA994IDR; SOIC8_D_TEX

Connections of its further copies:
+15V: C68.1, U22.12 (+), U24.7 (VCC+); also elsewhere on the board
-15V: C67.2, R58.1, U22.11 (-), U24.4 (VCC-); also elsewhere on the board
/Three Phase/Circuit_Measuring1/3_9: U22.3 (IN), U22.9 (OUT), U22.10 (OUT)
/Three Phase/Circuit_Measuring1/4_8: U22.4 (IN), U22.5 (IN), U22.8 (OUT)
/Three Phase/V: U22.1 (IN), U22.2 (IN); also elsewhere on the board
/Three Phase/V_ADC: R69.2, R70.2, U24.6 (OUT); also elsewhere on the board
/Three Phase/V_OUT: U22.6 (OUT), U22.7 (OUT); also elsewhere on the board
GND: C67.1, C68.2, R61.2, Rm2.2, U20.2 (K), U24.3 (IN+); also elsewhere on the board
unnamed: R58.2, R62.1, R64.2, U20.3 (A)
unnamed: R61.1, R62.2, U20.1 (FB)
unnamed: R66.1, Rm2.1, U22.13 (M)
unnamed: R64.1, R66.2, R69.1, R70.1, U24.2 (IN-)

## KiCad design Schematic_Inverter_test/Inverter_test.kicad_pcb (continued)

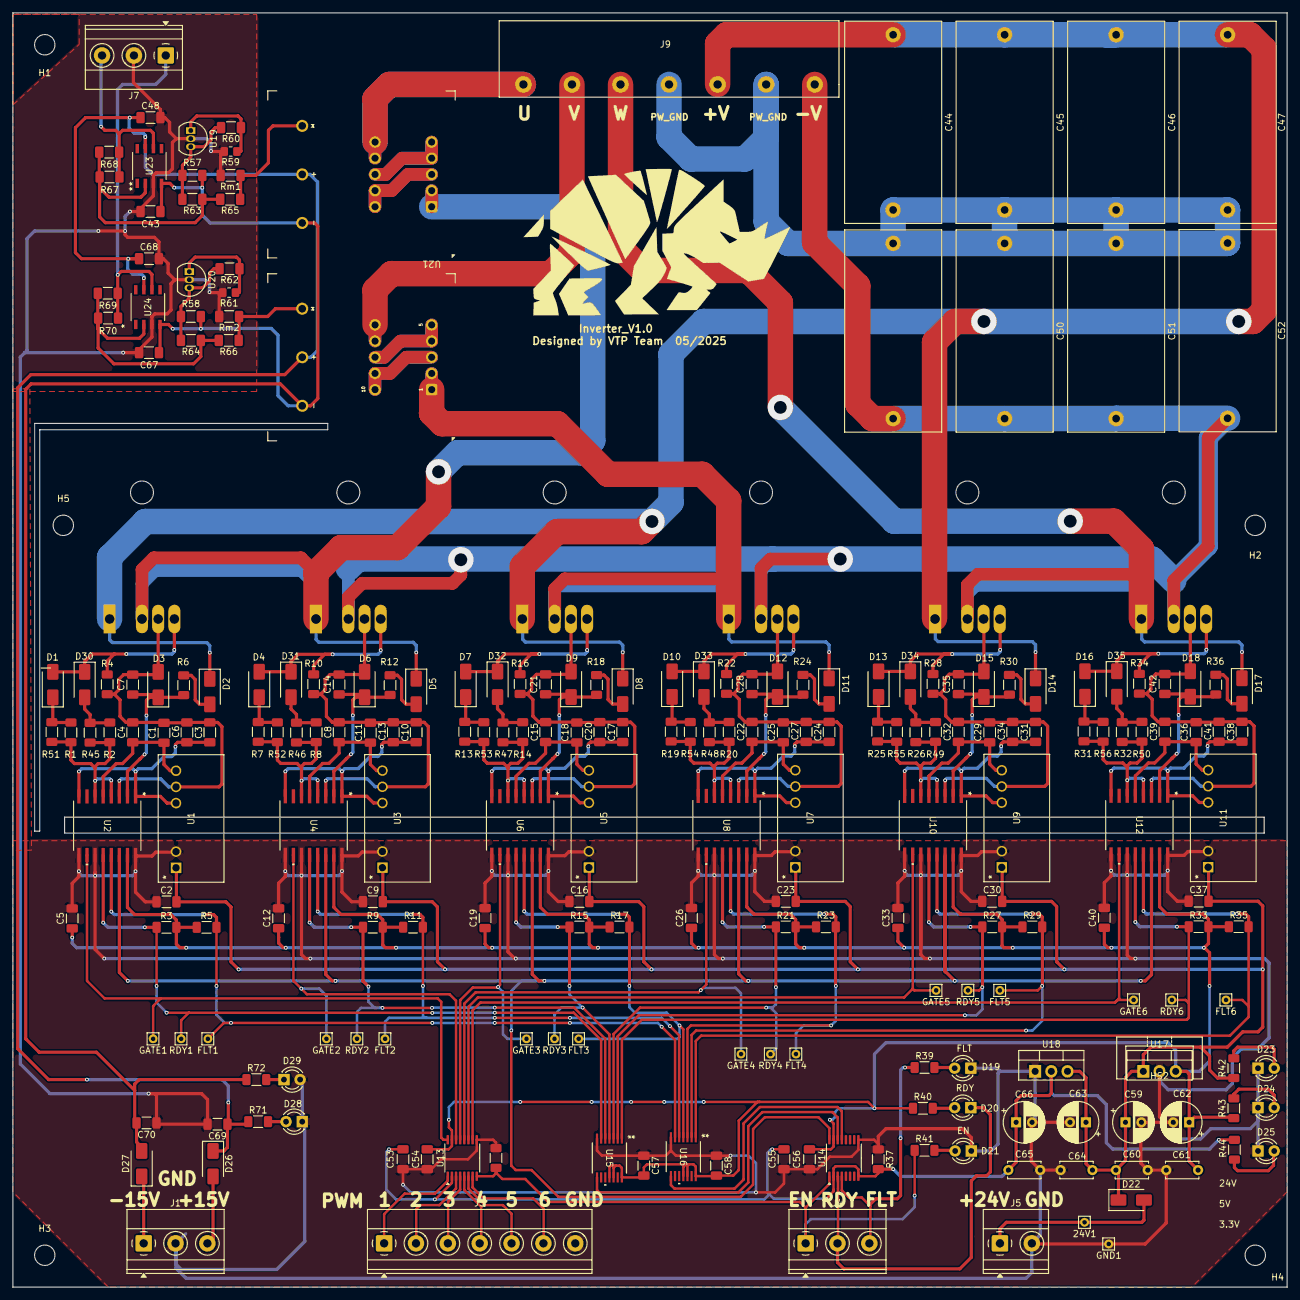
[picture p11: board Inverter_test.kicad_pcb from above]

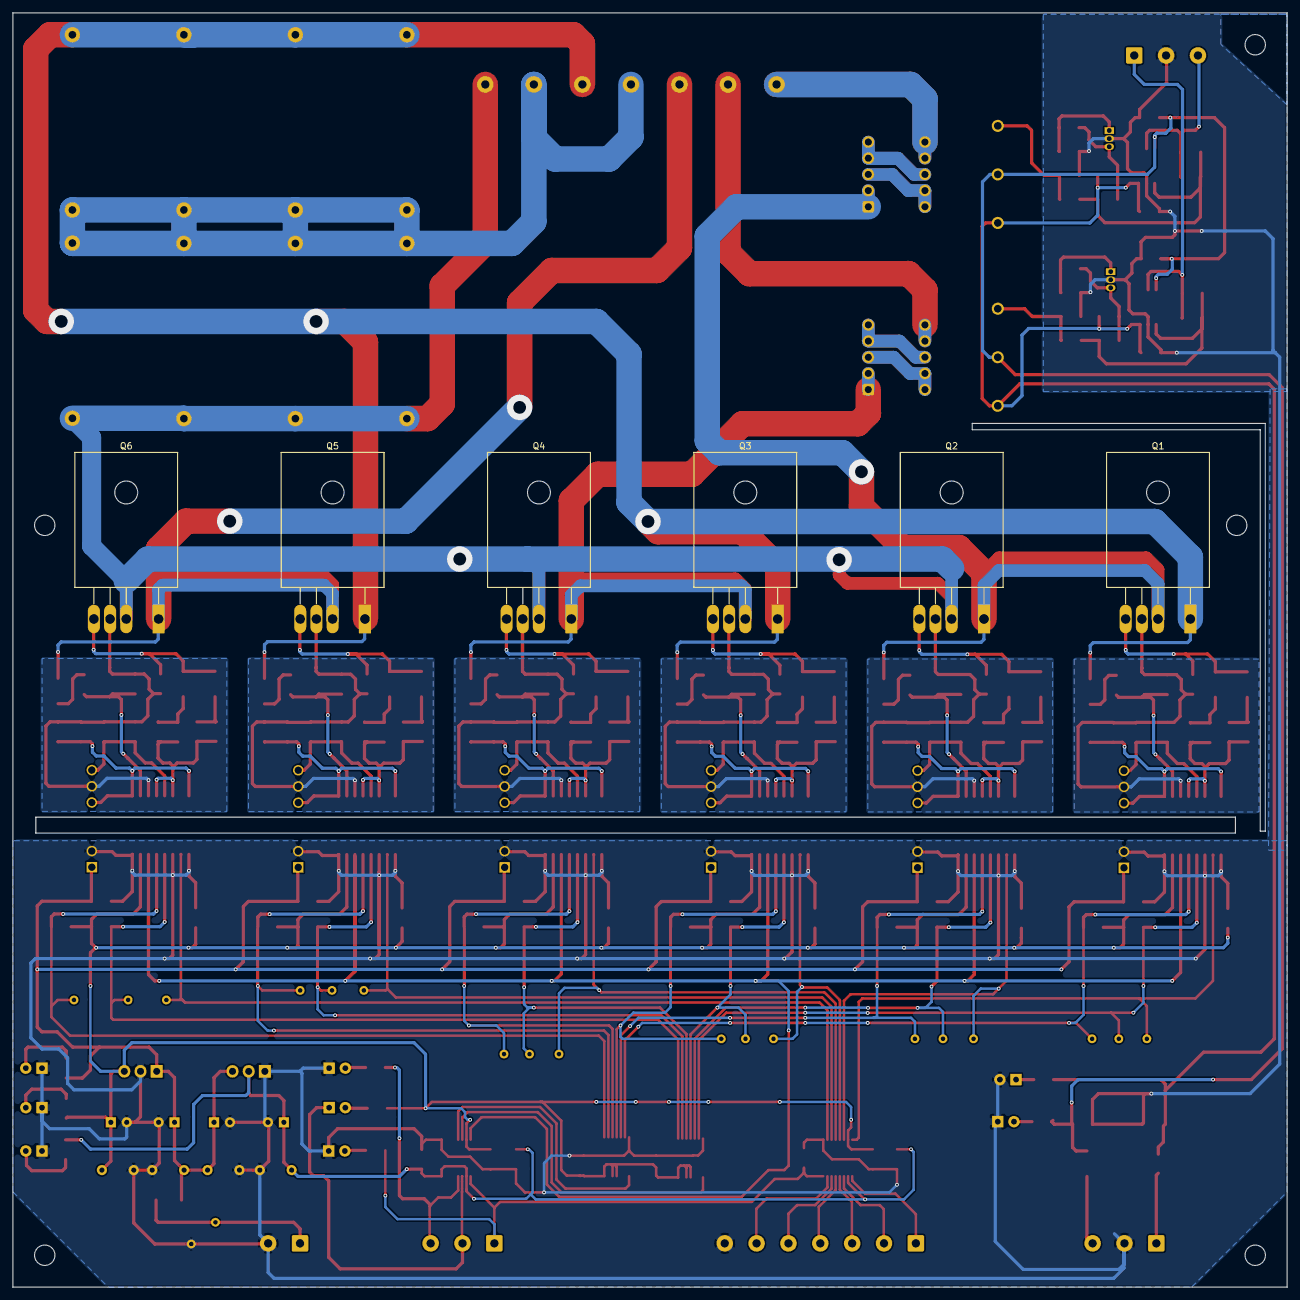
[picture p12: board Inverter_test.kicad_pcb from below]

Board: 2 copper layers, 200.0 x 200.0 mm, 241 parts (6 on the bottom side), 123 nets.

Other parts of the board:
HS2: Heatsink; Heatsink_Stonecold_HS-S01_13.21x6.35mm

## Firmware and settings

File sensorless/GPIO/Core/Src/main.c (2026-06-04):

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
/* Includes ------------------------------------------------------------------*/
#include "main.h"
#include "adc.h"
#include "dma.h"
#include "tim.h"
#include "usart.h"
#include "gpio.h"

/* USER CODE BEGIN Includes */
#include "arm_math.h"
#include "stdbool.h"
#include "stdio.h"
#include "stdlib.h"
#include "string.h"
#include "sensor.h"
#include "adc_driver.h"
#include "svpwm.h"
#include "uart_dma_lib.h"
#include "pid.h"
#include "foc_transform.h"
#include "pi_control.h"
#include "scurve_ramp.h"
#include "multi_ramp.h"
#include "smo.h"
#include "LPF.h"


/* USER CODE END Includes */

/* USER CODE BEGIN PTD */
/*PID*/
PID_HandleTypeDef pid_speed;
PID_HandleTypeDef pid_id;
PID_HandleTypeDef pid_iq;

PI_Clamping pi_speed;
PI_Clamping pi_id;
PI_Clamping pi_iq;
SCurve_Profile s_ramp;
MultiRamp_Gen ramp;
/* USER CODE END PTD */


/* USER CODE BEGIN PV */
		/* Sensor variables */
float elec_angle_rad_hall;          /* Electrical angle (rad) */
float elec_angle_rad_encoder;          
float mech_angle_rad_encoder;          /* Mechanical angle (rad) */
float mech_angle_deg;
float elec_angle_deg; 
float raw_angle;


uint8_t hall_step;             /* Current Hall step (1..6) */

/* Current measurement variables */
float iu, iv,iw;                  								 /* Phase A, B,C currents (A) */

float i_alpha, i_beta , v_alpha , v_beta;          /* Stationary frame currents */

float i_d = 0 , i_q = 0 , i_q_ref = 0 , i_d_ref = 0;             /* Rotating frame currents */
   

float v_d = 0.0f , v_q = 0.0f;

uint8_t state = 0;

int state_Z=0;

int dir =1;
float threshold;

/*PID*/
float speed_mechanic_rad;
float speed_ref_rpm = 1000.0f;      // T?c d? d?t (RPM)
float speed_mechanic_rpm = 0.0f;    // T?c d? h?i ti?p (RPM)
float speed_ref_rads = 100.0f; // setpoint speed rad/s

//smo
float theta_e, omega_e;
float error_theta;
float ss_openloop_timer = 0.0f;   // Bộ đếm thời gian trong pha open‑loop (giây)
float ss_openloop_speed = 0.0f;   // Tốc độ ảo tăng dần (rad/s)
//smo
typedef enum {
    SS_ALIGN = 0,
    SS_OPENLOOP,
    SS_SWITCH,
    SS_RUN
} SensorlessSubState;

SensorlessSubState state_smo = SS_ALIGN;
float ss_align_timer = 0.0f;
float ss_openloop_theta = 0.0f;
float ss_openloop_omega = 0.0f;
float ss_switch_timer = 0.0f;

SMO_Handle smo;                 // Đối tượng SMO toàn cục
float theta_smo, omega_smo;     // Góc và tốc độ từ SMO
float speed_mechanic_rad_smo;

LPF_FirstOrder_t LPF; 
/* USER CODE END PV */

void SystemClock_Config(void);
static void MPU_Config(void);
/* USER CODE BEGIN PFP */
void Calib(void);
void Align_Process(void);
float value_offset;
/* USER CODE END PFP */

/* USER CODE BEGIN 0 */
/* FOC loop interrupt (e.g., 10 kHz) */

void HAL_TIM_PeriodElapsedCallback(TIM_HandleTypeDef *htim)
{
    if (htim->Instance == TIM6)   // FOC loop (10kHz)
    {
				value_offset =ADC_Driver_GetOffset_IV();
        elec_angle_rad_hall = Sensor_Get_Electrical_Angle_Hall();
				
				raw_angle = Encoder_Get_Raw_Angle();
				elec_angle_rad_encoder = Encoder_Get_Electric_Angle();
				mech_angle_rad_encoder = Encoder_Get_Mechanic_Angle();
				hall_step = Hall_GetStep();
			
        
				speed_mechanic_rad = Encoder_Get_Mechanic_Speed();
        float omega_e = speed_mechanic_rad * POLE_PAIRS;

        // ----- D? do�n g�c di?n (b� tr?) -----
        float Ts = 1.0f / MOTOR_SPEED_CALC_FREQ;          // 25e-6 s
        float t_delay = 3.87e-6f;                         // 3.87 �s
        float theta_pred = elec_angle_rad_encoder + omega_e * (Ts + t_delay);
        theta_pred = fmodf(theta_pred, 2.0f * M_PI);
        if (theta_pred < 0.0f) theta_pred += 2.0f * M_PI;
        
        iu = ADC_Driver_GetCurrents_1();
        iv = ADC_Driver_GetCurrents_2();
        iw = ADC_Driver_GetCurrents_3();
				

				  if (state == 1) 
					{
						HAL_GPIO_WritePin(GPIOF, GPIO_PIN_9, GPIO_PIN_SET);
					FOC_InvPark(0.8, 0, 0, &v_alpha, &v_beta);
					SVPWM_Update(v_alpha, v_beta, iu, iv, iw); 
					Encoder_Reset();
					v_d=0;
					v_q=0;	
					} 
					else if (state==2) {
						HAL_GPIO_WritePin(GPIOF, GPIO_PIN_9, GPIO_PIN_SET);
					HAL_GPIO_WritePin(GPIOG, GPIO_PIN_2, GPIO_PIN_SET);
					//SCurve_Update(&s_ramp, speed_ref_rads);
					MultiRamp_Update(&ramp,speed_ref_rads);

					FOC_Clarke(iu, iv, iw, &i_alpha, &i_beta);
					FOC_Park(i_alpha, i_beta, elec_angle_rad_encoder, &i_d, &i_q);


					i_q_ref = PID_Compute(&pid_speed, speed_ref_rads, speed_mechanic_rad);
					v_q = PID_Compute(&pid_iq, i_q_ref, i_q);
					v_d = PID_Compute(&pid_id, 0,i_d);
						
//						i_q_ref = PI_Update(&pi_speed,speed_ref_rads,speed_mechanic_rad);
//						v_q = PI_Update(&pi_iq,i_q_ref, i_q);
//						v_d = PI_Update(&pi_id,0, i_d);
					FOC_InvPark(v_d, v_q, elec_angle_rad_encoder, &v_alpha, &v_beta);
					SVPWM_Update(v_alpha, v_beta, iu, iv, iw);
						
				
					HAL_GPIO_WritePin(GPIOG, GPIO_PIN_2, GPIO_PIN_RESET);	

					}	
					else if(state ==3){
						HAL_GPIO_WritePin(GPIOF, GPIO_PIN_9, GPIO_PIN_SET);
						FOC_InvPark(v_d, v_q, elec_angle_rad_encoder, &v_alpha, &v_beta);
						SVPWM_Update(v_alpha, v_beta, iu, iv, iw);
					}
else if (state == 4) {
    HAL_GPIO_WritePin(GPIOF, GPIO_PIN_9, GPIO_PIN_SET);
    float dt = 1.0f / MOTOR_SPEED_CALC_FREQ;

    // 1. Clarke Transform
    FOC_Clarke(iu, iv, iw, &i_alpha, &i_beta);
		MultiRamp_Update(&ramp,speed_ref_rads);
    float id_ref_local = 0.0f;
    float iq_ref_local = 0.0f;

    // ====================== SENSORLESS STARTUP STATE MACHINE ======================
    switch (state_smo) {
        case SS_ALIGN: {
            // Rotor alignment (Id = 0.8A, Iq = 0, theta = 0)
            theta_e = 0.0f;
            omega_e = 0.0f;
            id_ref_local = 0.8f;
            iq_ref_local = 0.0f;

            ss_align_timer += dt;
            if (ss_align_timer >= 1.0f) {          // Align trong 1 giây
                state_smo = SS_OPENLOOP;
                ss_openloop_timer = 0.0f;
                ss_openloop_speed = 0.0f;
                ss_align_timer = 0.0f;
            }
            break;
        }

        case SS_OPENLOOP: {
            // Open-loop ramp-up
            ss_openloop_speed += 100.0f * dt;       // Gia tốc ~80 rad/s² (có thể chỉnh)
            ss_openloop_timer += dt;

            theta_e = ss_openloop_speed * ss_openloop_timer;   // theta = integral(omega)
            omega_e = ss_openloop_speed;

            id_ref_local = 0.0f;
            iq_ref_local = speed_ref_rads * 0.015f;   // Iq nhỏ để kéo động

            // Chuyển sang SWITCH khi đạt omega_min
            if (ss_openloop_speed >= smo.omega_min) {
                state_smo = SS_RUN;
                ss_switch_timer = 0.0f;
            }
            break;
        }

        case SS_SWITCH: {
            // Giữ open-loop thêm một khoảng thời gian để SMO hội tụ
            theta_e = ss_openloop_speed * ss_openloop_timer;
            omega_e = ss_openloop_speed;
            id_ref_local = 0.0f;
            iq_ref_local = speed_ref_rads * 0.015f;

            if (fabsf(smo.ialpha_est - i_alpha) < 0.001f &&
                fabsf(smo.ibeta_est - i_beta) < 0.001f) {
                state_smo = SS_RUN;
            }

            break;
        }

        case SS_RUN: {
            // Full sensorless - dùng SMO
            theta_e = SMO_GetCompensatedTheta(&smo);
            omega_e = LPF_FirstOrder_Update(&LPF,SMO_GetOmega(&smo));
					
            id_ref_local = 0.0f;
            speed_mechanic_rad_smo = omega_e / POLE_PAIRS;
            iq_ref_local = PID_Compute(&pid_speed, speed_ref_rads, speed_mechanic_rad_smo);
            break;
        }
    }

    // ====================== CURRENT CONTROL ======================
    FOC_Park(i_alpha, i_beta, theta_e, &i_d, &i_q);

    v_d = PID_Compute(&pid_id, id_ref_local, i_d);
    v_q = PID_Compute(&pid_iq, iq_ref_local, i_q);

    FOC_InvPark(v_d, v_q, theta_e, &v_alpha, &v_beta);

    // ====================== UPDATE SMO & PWM ======================
    SMO_Update(&smo, v_alpha, v_beta, i_alpha, i_beta, dt);

    SVPWM_Update(v_alpha, v_beta, iu, iv, iw);

    // Optional: monitor error
    error_theta = elec_angle_rad_encoder - theta_e  ;
}

					else if(state ==0){
						

						
						HAL_GPIO_WritePin(GPIOF, GPIO_PIN_9, GPIO_PIN_RESET);
						v_alpha = 0.0f; v_beta = 0.0f;
						SVPWM_Update(v_alpha, v_beta, iu, iv, iw);
						// Reset sensorless state
						state_smo = SS_ALIGN;
						ss_align_timer = 0.0f;
					}
    }
		else if (htim->Instance == TIM3)
		{
			EncoderSensor_Update();
		}
}

void HAL_TIM_IC_CaptureCallback(TIM_HandleTypeDef *htim)
{
    if (htim->Instance == TIM5 && htim->Channel == HAL_TIM_ACTIVE_CHANNEL_3)
    {
        uint32_t cap_val = HAL_TIM_ReadCapturedValue(&htim5, TIM_CHANNEL_3);
        Encoder_Capture_Handler(cap_val);
    }
    else if (htim->Instance == TIM4 && htim->Channel == HAL_TIM_ACTIVE_CHANNEL_1)
    {
        HallSensor_Update();
    }
    else if (htim->Instance == TIM12)
    {
        // Z-pulse nếu cần
    }
}


/* USER CODE END 0 */

/**
  * @brief  The application entry point.
  * @retval int
  */
int main(void)
{

  /* MPU Configuration--------------------------------------------------------*/
  MPU_Config();

  /* MCU Configuration--------------------------------------------------------*/

  /* Reset of all peripherals, Initializes the Flash interface and the Systick. */
  HAL_Init();

  /* Configure the system clock */
  SystemClock_Config();

  /* Initialize all configured peripherals */
  MX_GPIO_Init();
  MX_DMA_Init();
  MX_TIM1_Init();
  MX_TIM3_Init();
  MX_TIM2_Init();
  MX_TIM4_Init();
  MX_TIM5_Init();
  MX_ADC1_Init();
  MX_ADC2_Init();
  MX_USART1_UART_Init();
  MX_TIM12_Init();
  MX_TIM6_Init();
  /* USER CODE BEGIN 2 */

		//center-alinge
		SVPWM_Init(&htim1, VDC_BUS, (float)MOTOR_PWM_FREQ, htim1.Init.Period);
		SVPWM_Start();
    HAL_TIM_Base_Start_IT(&TIM_FOC_LOOP);
		HAL_TIM_Base_Start_IT(&TIM_SPEED_CALC);
		/* ======================== ADC sensor ======================== */
		ADC_Driver_Init();
		ADC_Driver_CalibrateOffset();
		/* ======================== Hall sensor ======================== */
		Hall_Sensor_Init();
		HallSensor_Update();
		/* ======================== Encoder sensor ======================== */
		Encoder_Sensor_Init();

		/* ======================== UART sensor ======================== */
		MX_USART1_UART_Init();   
		UART_DMA_Init();   
		UART_DMA_SendString("UART DMA with IDLE+HT/TC ready\r\n");
		/* ======================== PID ======================== */
			
		PID_Init(&pid_iq, 8.0f, 1749.0f, 0.0f, 1/MOTOR_SPEED_CALC_FREQ , VDC_BUS/SQRT3, -VDC_BUS/SQRT3);
		PID_Init(&pid_id, 8.0f, 1749.0f, 0.0f, 1/MOTOR_SPEED_CALC_FREQ , VDC_BUS/SQRT3, -VDC_BUS/SQRT3);
		PID_Init(&pid_speed, 0.0053f, 2.37f, 0.0f, 1/MOTOR_SPEED_CALC_FREQ, 2.8f, -2.8f); 
		//PID_Init(&pid_speed, 0.0053f, 4.0f, 0.0f, 1/MOTOR_SPEED_CALC_FREQ, 2.8f, -2.8f); 
		
		PI_Init(&pi_speed,0.1125,0.9375,1/MOTOR_SPEED_CALC_FREQ,10.0f,-10.0f);
		PI_Init(&pi_id,237.6697,11330,1/MOTOR_SPEED_CALC_FREQ,VDC_BUS/SQRT3,-VDC_BUS/SQRT3);
		PI_Init(&pi_iq,237.6697,11330,1/MOTOR_SPEED_CALC_FREQ,VDC_BUS/SQRT3,-VDC_BUS/SQRT3);
		
		SCurve_Init(&s_ramp,1/MOTOR_SPEED_CALC_FREQ,1,1,1);
		
		MultiRamp_Init(&ramp,1/MOTOR_SPEED_CALC_FREQ,5,10,10,20,20);
		/* ======================== SMO ======================== */
		
		SMO_Init(&smo, MOTOR_RS, MOTOR_LS, MOTOR_PSI_F, POLE_PAIRS,3000.0f, 300.0f, 1.0f / MOTOR_SPEED_CALC_FREQ);
		LPF_FirstOrder_Init(&LPF,1000,1.0f / MOTOR_SPEED_CALC_FREQ);
  /* USER CODE END 2 */

  /* Infinite loop */
  /* USER CODE BEGIN WHILE */
     while (1)
    {
		
    /* USER CODE END WHILE */

    /* USER CODE BEGIN 3 */


    }
  /* USER CODE END 3 */
}

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
 /* MPU Configuration */

void MPU_Config(void)
{
  MPU_Region_InitTypeDef MPU_InitStruct = {0};

  /* Disables the MPU */
  HAL_MPU_Disable();

  /** Initializes and configures the Region and the memory to be protected
  */
  MPU_InitStruct.Enable = MPU_REGION_ENABLE;
  MPU_InitStruct.Number = MPU_REGION_NUMBER0;
  MPU_InitStruct.BaseAddress = 0x0;
  MPU_InitStruct.Size = MPU_REGION_SIZE_4GB;
  MPU_InitStruct.SubRegionDisable = 0x87;
  MPU_InitStruct.TypeExtField = MPU_TEX_LEVEL0;
  MPU_InitStruct.AccessPermission = MPU_REGION_NO_ACCESS;
  MPU_InitStruct.DisableExec = MPU_INSTRUCTION_ACCESS_DISABLE;
  MPU_InitStruct.IsShareable = MPU_ACCESS_SHAREABLE;
  MPU_InitStruct.IsCacheable = MPU_ACCESS_NOT_CACHEABLE;
  MPU_InitStruct.IsBufferable = MPU_ACCESS_NOT_BUFFERABLE;

  HAL_MPU_ConfigRegion(&MPU_InitStruct);
  /* Enables the MPU */
  HAL_MPU_Enable(MPU_PRIVILEGED_DEFAULT);

}

/**
  * @brief  This function is executed in case of error occurrence.
  * @retval None
  */
void Error_Handler(void)
{
  /* USER CODE BEGIN Error_Handler_Debug */
    /* User can add his own implementation to report the HAL error return state */
    __disable_irq();
    while (1)
    {
    }
  /* USER CODE END Error_Handler_Debug */
}
#ifdef USE_FULL_ASSERT
/**
  * @brief  Reports the name of the source file and the source line number
  *         where the assert_param error has occurred.
  * @param  file: pointer to the source file name
  * @param  line: assert_param error line source number
  * @retval None
  */
void assert_failed(uint8_t *file, uint32_t line)
{
  /* USER CODE BEGIN 6 */
    /* User can add his own implementation to report the file name and line number,
       ex: printf("Wrong parameters value: file %s on line %d\r\n", file, line) */
  /* USER CODE END 6 */
}
#endif /* USE_FULL_ASSERT */

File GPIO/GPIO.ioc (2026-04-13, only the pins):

Mcu.UserName=STM32H723ZGTx
PA0.Signal=S_TIM2_CH1_ETR
PA1.Signal=S_TIM2_CH2
PA10.Signal=USART1_RX
PA13(JTMS/SWDIO).Signal=DEBUG_JTMS-SWDIO
PA14(JTCK/SWCLK).Signal=DEBUG_JTCK-SWCLK
PA9.Signal=USART1_TX
PB14.Signal=S_TIM12_CH1
PD12.Signal=S_TIM4_CH1
PD13.Signal=S_TIM4_CH2
PD14.Signal=S_TIM4_CH3
PE10.Signal=TIM1_CH2N
PE11.Signal=S_TIM1_CH2
PE12.Signal=TIM1_CH3N
PE13.Signal=S_TIM1_CH3
PE8.Signal=TIM1_CH1N
PE9.Signal=S_TIM1_CH1
PF11.Signal=ADC1_INP2
PF13.Signal=ADC2_INP2
PF9.Signal=GPIO_Output
PH0-OSC_IN.Signal=RCC_OSC_IN
PH1-OSC_OUT.Signal=RCC_OSC_OUT

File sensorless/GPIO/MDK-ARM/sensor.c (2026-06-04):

#include "sensor.h"

/* ------------------- Hall sensor (gi? nguyên) ------------------- */
HallSensor_t hall_sensor = {0};

static const float hall_angle_table[7] = {
    0.0f,
    0.0f * (M_PI / 180.0f),
    60.0f * (M_PI / 180.0f),
    120.0f * (M_PI / 180.0f),
    180.0f * (M_PI / 180.0f),
    240.0f * (M_PI / 180.0f),
    300.0f * (M_PI / 180.0f)
};

static uint8_t Hall_CalculateStep(uint8_t raw) {
    switch (raw) {
        case 0b101: return 1;
        case 0b100: return 2;
        case 0b110: return 3;
        case 0b010: return 4;
        case 0b011: return 5;
        case 0b001: return 6;
        default:    return 0;
    }
}

static void Hall_Update_Internal(void) {
    uint8_t u = HAL_GPIO_ReadPin(HALL_GPIO_PORT, HALL_U_PIN);
    uint8_t v = HAL_GPIO_ReadPin(HALL_GPIO_PORT, HALL_V_PIN);
    uint8_t w = HAL_GPIO_ReadPin(HALL_GPIO_PORT, HALL_W_PIN);
    hall_sensor.raw = (u << 2) | (v << 1) | w;
    hall_sensor.step = Hall_CalculateStep(hall_sensor.raw);
    if (hall_sensor.step != 0 && hall_sensor.step <= 6) {
        hall_sensor.angle_elec_hall = hall_angle_table[hall_sensor.step];
    }
}

void Hall_Sensor_Init(void) {
    HAL_TIMEx_HallSensor_Start_IT(&TIM_HALL);
    Hall_Update_Internal();
}

void HallSensor_Update(void) {
    Hall_Update_Internal();
}

float Sensor_Get_Electrical_Angle_Hall(void) {
    return hall_sensor.angle_elec_hall;
}

uint8_t Hall_GetStep(void) {
    return hall_sensor.step;
}

/* ------------------- Encoder implementation (TIM2 encoder, TIM3 gate, TIM5 capture) ------------------- */
Encoder_t encoder = {0};

static int64_t encoder_last_cnt = 0;
static int64_t encoder_accumulator = 0;
static int64_t last_count_M = 0;

static float rpm_M = 0.0f;
static float rpm_T = 0.0f;

static SpeedMethod_t current_method = SPEED_METHOD_AUTO;

/* Bi?n cho T-method (TIM5 capture) */
static uint32_t last_capture = 0;
static uint32_t capture_period = 0;
static uint8_t  capture_valid = 0;

/* H? tr? d?u cho T-method: luu hu?ng g?n nh?t */
static int8_t  direction_sign = 1;   // +1 ho?c -1

#define M_THRESHOLD     100
#define T_THRESHOLD     10
#define FT_FREQ_HZ      1000000.0f

void Encoder_Sensor_Init(void) {
    HAL_TIM_Encoder_Start(&TIM_ENCODER, TIM_CHANNEL_ALL);
    __HAL_TIM_SET_COUNTER(&TIM_ENCODER, 0);

    HAL_TIM_Base_Start_IT(&htim3);           // gate 1ms
    HAL_TIM_IC_Start_IT(&htim5, TIM_CHANNEL_3); // capture

    encoder.raw_count = 0;
    encoder.mech_angle = 0.0f;
    encoder.elec_angle = 0.0f;
    encoder.mech_speed = 0.0f;
    encoder.elec_speed = 0.0f;
    encoder.rpm = 0.0f;

    encoder_last_cnt = 0;
    encoder_accumulator = 0;
    last_count_M = 0;
    last_capture = 0;
    capture_period = 0;
    capture_valid = 0;
    direction_sign = 1;
}
static inline float Normalize_Angle(float angle)
{
    while (angle >= TWO_PI)
        angle -= TWO_PI;

    while (angle < 0.0f)
        angle += TWO_PI;

    return angle;
}
static void Encoder_Update_Position(void) {
    int64_t current_cnt = (int64_t)__HAL_TIM_GET_COUNTER(&TIM_ENCODER);
    int64_t delta = current_cnt - encoder_last_cnt;

    if (delta > 2147483647LL) {
        delta -= 4294967296ULL;
    } else if (delta < -2147483647LL) {
        delta += 4294967296ULL;
    }

    encoder_accumulator += delta;
    encoder.raw_count = encoder_accumulator;
    encoder_last_cnt = current_cnt;

    encoder.mech_angle = (float)((double)encoder.raw_count * (2.0 * M_PI) / ENCODER_COUNTS_PER_REV);
    encoder.mech_angle = fmodf(encoder.mech_angle, (float)(2.0 * M_PI));
    if (encoder.mech_angle < 0) encoder.mech_angle += (float)(2.0 * M_PI);
		//encoder.mech_angle = Normalize_Angle(encoder.mech_angle);
		
		
    encoder.elec_angle = encoder.mech_angle * POLE_PAIRS;
    encoder.elec_angle = fmodf(encoder.elec_angle, (float)(2.0 * M_PI));
    if (encoder.elec_angle < 0) encoder.elec_angle += (float)(2.0 * M_PI);
		//encoder.elec_angle = Normalize_Angle(encoder.elec_angle);
}


static float Calculate_RPM_M(int64_t delta_count, float gate_time_s) {
    if (gate_time_s <= 0.0f) return 0.0f;
    return (delta_count * 60.0f) / (ENCODER_COUNTS_PER_REV * gate_time_s);
}

static float Calculate_RPM_T(uint32_t period_us) {
    if (period_us == 0) return 0.0f;
    return (60.0f * FT_FREQ_HZ) / (2500 * (float)period_us);
}

void EncoderSensor_Update(void) {
    Encoder_Update_Position();

    const float Ts = 1.0f / MOTOR_SPEED_CALC_FREQ_FOR_ENCODER;
    int64_t delta_M = encoder.raw_count - last_count_M;
    last_count_M = encoder.raw_count;

    // Xác d?nh hu?ng t? delta_M (dùng cho T-method)
    if (delta_M > 0) direction_sign = 1;
    else if (delta_M < 0) direction_sign = -1;

    // M-method (có d?u)
    rpm_M = Calculate_RPM_M(delta_M, Ts);

    // T-method (luôn duong, sau dó gán d?u)
    uint32_t period = capture_period;
    if (capture_valid) {
        float abs_rpm_T = Calculate_RPM_T(period);
        rpm_T = direction_sign * abs_rpm_T;   // thêm d?u
        capture_valid = 0;
    }

    // L?a ch?n phuong pháp
    float selected_rpm = 0.0f;
    int64_t abs_delta = (delta_M >= 0) ? delta_M : -delta_M;

    switch (current_method) {
        case SPEED_METHOD_M:   selected_rpm = rpm_M; break;
        case SPEED_METHOD_T:   selected_rpm = rpm_T; break;
        case SPEED_METHOD_AUTO:
        default:
            if (abs_delta >= M_THRESHOLD)      selected_rpm = rpm_M;
            else if (abs_delta <= T_THRESHOLD) selected_rpm = rpm_T;
            else                               selected_rpm = (rpm_M + rpm_T) / 2.0f;
            break;
    }

    encoder.rpm = selected_rpm;
    encoder.mech_speed = selected_rpm * (2.0f * M_PI) / 60.0f;
    encoder.elec_speed = encoder.mech_speed * POLE_PAIRS;
}

void Encoder_Capture_Handler(uint32_t capture_value) {
    if (last_capture != 0) {
        uint32_t diff;
        if (capture_value >= last_capture) {
            diff = capture_value - last_capture;
        } else {
            diff = (0xFFFFFFFF - last_capture) + capture_value + 1;
        }
        capture_period = diff;
        capture_valid = 1;
    }
    last_capture = capture_value;
}

float Encoder_Get_Raw_Angle(void) { return (float)encoder.raw_count; }
float Encoder_Get_Electric_Angle(void) { return encoder.elec_angle; }
float Encoder_Get_Mechanic_Angle(void) { return encoder.mech_angle; }
float Encoder_Get_Mechanic_Speed(void) { return encoder.mech_speed; }
float Encoder_Get_Electric_Speed(void) { return encoder.elec_speed; }
float Encoder_Get_RPM(void) { return encoder.rpm; }

void Encoder_Reset(void) {
    __HAL_TIM_SET_COUNTER(&TIM_ENCODER, 0);
    encoder_accumulator = 0;
    encoder_last_cnt = 0;
    encoder.raw_count = 0;
    encoder.mech_angle = 0.0f;
    encoder.elec_angle = 0.0f;
    encoder.mech_speed = 0.0f;
    encoder.elec_speed = 0.0f;
    encoder.rpm = 0.0f;
    last_count_M = 0;
    last_capture = 0;
    capture_period = 0;
    capture_valid = 0;
    direction_sign = 1;
}
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

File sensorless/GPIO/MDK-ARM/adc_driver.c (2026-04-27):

/**
  * @file    adc_driver.c
  * @brief   Implementation of ADC driver for LA-25-NP
  */

#include "adc_driver.h"



static volatile uint32_t raw_iu = 0;
static volatile uint32_t raw_iv = 0;
static volatile float current_iu = 0.0f;
static volatile float current_iv = 0.0f;
static volatile float current_iw = 0.0f;

static volatile float raw_offset_iu = 0.0f;
static volatile float raw_offset_iv = 0.0f;


/* Convert raw ADC value to current (A) */
static float raw_to_current(uint32_t raw, float raw_offset)
{
    float raw_corrected = (float)raw - raw_offset;
    float v_adc = (raw_corrected * ADC_VREF / ADC_RESOLUTION )+1.25f; //calib
    float i = LA25NP_V_TO_I(v_adc);
    return i;
}
void ADC_Driver_CalibrateOffset(void)
{
    uint32_t sum_iu = 0;
    uint32_t sum_iv = 0;

    for (int i = 0; i < (int)ADC_CALIB_SAMPLES; i++)
    {
        sum_iu += HAL_ADCEx_InjectedGetValue(&hadc1, ADC_INJECTED_RANK_1);
        sum_iv += HAL_ADCEx_InjectedGetValue(&hadc2, ADC_INJECTED_RANK_1);
    }

    raw_offset_iu = (float)sum_iu / ADC_CALIB_SAMPLES;
    raw_offset_iv = (float)sum_iv / ADC_CALIB_SAMPLES;
}

/* Initialize and start ADC conversions */
void ADC_Driver_Init(void)
{

			HAL_ADCEx_Calibration_Start(&hadc1,ADC_CALIB_OFFSET_LINEARITY,ADC_SINGLE_ENDED);
	HAL_ADCEx_Calibration_Start(&hadc2,ADC_CALIB_OFFSET_LINEARITY,ADC_SINGLE_ENDED);
			HAL_ADC_Start(&hadc2);
			HAL_ADC_Start(&hadc1);
    /* Start injected conversions with interrupt */
			HAL_ADCEx_InjectedStart_IT(&hadc2);
	    HAL_ADCEx_InjectedStart_IT(&hadc1);

}



/* Injected conversion complete callback ? called by HAL from ADC_IRQHandler */
void HAL_ADCEx_InjectedConvCpltCallback(ADC_HandleTypeDef* hadc)
{
    if (hadc->Instance == ADC1)
    {
        raw_iu = HAL_ADCEx_InjectedGetValue(&hadc1, ADC_INJECTED_RANK_1);
        raw_iv = HAL_ADCEx_InjectedGetValue(&hadc2, ADC_INJECTED_RANK_1);
		}
}
/* Get the latest current values  */
float ADC_Driver_GetCurrents_1(void)
{
    current_iu = raw_to_current(raw_iu, raw_offset_iu);
    return current_iu;
}

float ADC_Driver_GetCurrents_2(void)
{
    current_iv = raw_to_current(raw_iv, raw_offset_iv);
    return current_iv;
}

float ADC_Driver_GetCurrents_3(void)
{
    current_iw = -current_iu - current_iv;
    return current_iw;
}

/*----------------------------------------------------------------------------
 * L?y offset (raw) – dùng d? ki?m tra
 *----------------------------------------------------------------------------*/
float ADC_Driver_GetOffset_IV(void)
{
    return raw_offset_iv;
}

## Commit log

2026-03-21 add function Pid
2026-03-25 change sensor
2026-04-07 run with encoder
2026-04-07 update sensor
2026-04-07 no encoder
2026-08-20 Create Schematic_Inverter
2026-08-20 Create Schematic_Inverte
2026-08-20 upadate schematic
    [Buffer-DESKTOP-FUAMFCB-2.kicad_sch, Buffer-DESKTOP-FUAMFCB.kicad_sch, Buffer.kicad_pcb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]
